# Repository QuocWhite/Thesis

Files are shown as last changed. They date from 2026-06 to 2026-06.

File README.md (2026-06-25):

# Quoc — Voice-Guided 6-DOF Robotic Arm Control System

Python-based control system for a **6-DOF pick-and-place robot arm** with voice commands, computer vision (YOLOv3), inverse kinematics, and ESP32 firmware (Arduino framework).

## System Overview

```
User Voice → Speech Recognition → Command Parsing → Object Detection (YOLO)
                                                       ↓
                                              Inverse Kinematics
                                                       ↓
                                            Serial → ESP32
                                                       ↓
                                           PCA9685 → 6 Servo Motors
```

## 6-DOF Joint Configuration (Denavit-Hartenberg)

| Joint | Name | Type | DH a (mm) | DH d (mm) | α | Serial Label |
|---|---|---|---|---|---|---|
| J1 | Base | Waist | 42 | 75 | +90° | `b` |
| J2 | Right | Shoulder | 95 | 0 | 0° | `r` |
| J3 | Left | Elbow | 18 | 0 | +90° | `l` |
| J4 | Twist | Wrist roll | 0 | 166 | -90° | `t` |
| J5 | Wrist | Wrist pitch | 0 | 0 | +90° | `w` |
| J6 | Finger | Gripper  | 0 | 27 | +180° | `f` |

## Project Structure

```
Quoc/
├── voice/                      Speech recognition (Google STT + noise reduction)
│   └── VoiceRecognization.py
├── vision/                     YOLOv3 object detection
│   ├── yolo.py                 2D detection → pixel coordinates
│   └── yolo3/                  YOLOv3 model architecture
├── kinematics/                 Forward & inverse kinematics
│   └── kinematics.py           DH parameters, Jacobian-based IK solver
├── actuator/                   ESP32 firmware (Arduino framework) & 3D print files
│   ├── ArmControl/             Firmware source (C++)
│   │   ├── ArmControl.ino      Entry point
│   │   ├── ArmControl.h        Configuration, pin assignments, class API
│   │   └── ArmControl.cpp      6-axis motion control, cubic trajectory, serial parser
│   └── Finger/                 3D-printable gripper STL files
├── command/                    Serial communication bridge
│   └── command_handeler.py     Sends joint data & commands to ESP32
├── Test/                       Host-side integration & unit tests
│   ├── test_system.py          Kinematics, serial bridge, voice parsing, pipeline, 3D viz
│   ├── test_armcontrol.py      Python port of firmware logic (18 unit/stress tests)
│   ├── armcontrol.py           Python port of firmware TrajectoryQueue
│   ├── Arm_IT_test.cpp         C++ host endurance test (10k steps)
│   ├── Arm                     Compiled C++ test binary
│   ├── arm_fk_plot.png         Generated 3D FK visualization
│   └── arm_ik_plot.png         Generated IK convergence plot
├── main.py                     Pipeline entry point
├── run_sys.sh                  Startup script (activates venv, runs main.py)
└── requirements.txt
```

## Firmware (ESP32)

### Communication Protocol

Serial at **115200 baud** on `/dev/ttyUSB0` (configurable).

**Joint angle format:** `b<base>r<right>l<left>t<twist>w<wrist>f<finger>\n`

Example: `b90r45l60t0w30f50\n` sets all 6 joints.

**Text commands:**
| Command | Action |
|---|---|
| `init` | Reset all joints to factory home |
| `report` | Print current joint positions |
| `test` | Run servo sweep test |
| `mcalib` | Read manual calibration data |
| `acalib` | Run auto calibration |

### Motion Control

- **Servo driver:** PCA9685 16-channel PWM controller (I²C)
- **Cubic trajectory interpolation:** Smooth point-to-point motion with configurable duration (150 ms per segment)
- **Trajectory queue:** 2D circular buffer (`queueBuffer_[MAX_JOINT][TRAJECTORY_QUEUE_SIZE]`) for multi-step sequences
- **Joint limits:** Configurable min/max pulse widths per joint via hardware trigger pins
- **EEPROM calibration:** Stores calibrated pulse ranges persistently

### Firmware Fixes Applied

The C++ firmware (`ArmControl.h`/`.cpp`) received the following fixes:
- **Dead macro removal:** 6 unused macros removed from `ArmControl.h`
- **Typo correction:** `MED_DEVIDE` renamed to `MIDPOINT_DIV`
- **Semantic rename:** 3 misleading names (`QUEUE_ERROR`→`QUEUE_ERR`, `UNAVAIL_SER`→`SER_ERR`, `INCREASE`→`INC_STEP`) — private methods in `ArmControl.cpp`
- **Private method naming:** 15 methods unified to camelCase convention
- **Integer overflow fix:** 5 overflow bugs in `computeCubicTrajectory_` fixed with `int64_t` casts to prevent wrap-around on large intermediate products
- **Output clamping:** Cubic interpolation results clamped to `[COMMON_MIN_ANGLE, COMMON_MAX_ANGLE]` to protect servos from overshoot

### Hardware Pin Mapping

Each joint has dedicated trigger pins for limit/calibration:

| Joint  | Min Pin | Max Pin | PCA9685 Channel |
|---|---|---|---|
| Base | 12 | 5 | 0 |
| Right  | 14 | 13 | 1 |
| Left | 19 | 18 | 2 |
| Twist  | 26 | 25 | 3 |
| Wrist  | 32 | 27 | 4 |
| Finger | 4 | 33 | 5 |

## Python Components

### Voice (`voice/VoiceRecognization.py`)
- Google Speech Recognition API
- Real-time noise reduction via `noisereduce`
- Keyword extraction for actions: *take, pick, grab, get*

### Vision (`vision/yolo.py`)
- YOLOv3 object detection (TensorFlow 2 / Keras)
- 2D pixel coordinates from webcam feed
- COCO dataset classes (80 object categories)

### Kinematics (`kinematics/kinematics.py`)
- Forward kinematics via DH parameter transformation matrices
- Inverse kinematics via Jacobian pseudoinverse (damped least-squares)
- Euler angle extraction from rotation matrices
- Configurable iteration count, tolerance, and learning rate
- Numerical Jacobian via finite-difference perturbation (fixed: input arrays auto-cast to float to prevent integer truncation of perturbations)

### Tests (`Test/`)
- **`test_system.py`** — 16 integration tests:
  - 4 kinematics tests: FK at zero (checking x≈155, y≈0, z≈−118 per DH convention), FK at known angles, IK roundtrip (solve → FK → error < 1.0), Jacobian shape (6×6) and rank validation
  - 3 serial bridge tests (mocked): protocol format verification, text commands, concatenated sends
  - 6 voice parsing tests (conditionally skipped without `noisereduce`): action/object extraction for *take/pick/grab/get*, case insensitivity, no-action
  - 1 full pipeline test: mocked voice → YOLO → IK → serial → roundtrip verification
  - 2 3D visualization tests: `arm_fk_plot.png` (3-configuration arm layout), `arm_ik_plot.png` (convergence curve + solved arm)
- **`test_armcontrol.py`** — 18 unit/stress tests for the Python firmware port (edge-case clamping, trajectory queue overflow, cubic interpolation)
- **`armcontrol.py`** — Python port of `TrajectoryQueue` with 2D circular buffer
- **`Arm_IT_test.cpp`** — C++ host endurance test (10k iterations, all 7 tests passing)

### Command Bridge (`command/command_handeler.py`)
- Serial communication with ESP32
- `send_joint_data(t1..t6)` — sends formatted joint angles
- `send_command(cmd)` — sends text commands
- Response reading and logging

## Setup

```bash
pip install -r requirements.txt
./run_sys.sh
```

Requires **Python 3.10+** and an **ESP32** running the firmware at `/dev/ttyUSB0` (configurable in `command/command_handeler.py`).

### Firmware Upload

1. Open `actuator/ArmControl/ArmControl.ino` in Arduino IDE
2. Install dependencies: `Adafruit PWMServoDriver` library
3. Select **ESP32 Dev Module** board (install ESP32 board support if needed)
4. Upload to the appropriate serial port (e.g. `/dev/ttyUSB0`)

## 3D-Printable Parts

Gripper STL files in `actuator/Finger/`:
- Palm (top & bottom)
- Finger pads & hinge arms
- Left/right gear arms
- Servo gear components

## Requirements

- Python 3.10+
- ESP32 (Arduino framework)
- PCA9685 servo driver
- 6× servo motors (with limit switches)
- USB webcam
- Microphone

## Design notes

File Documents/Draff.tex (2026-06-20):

\documentclass[12pt,a4paper]{report}

\usepackage{tikz}
\usepackage{amsmath}
\usepackage{listings}
\usepackage{hyperref}
\usepackage{geometry}
\geometry{margin=1in}

\title{Robotic Arm Thesis\\Actuator Subsystem Report}
\author{Your Name}
\date{\today}

\begin{document}

\maketitle

\tableofcontents

\chapter{Actuator System: Firmware Architecture and Control Algorithms}

\section{Introduction}
The actuator subsystem is implemented on an Arduino-compatible microcontroller, utilizing the Adafruit PCA9685 16-channel PWM driver for servo control. Its main function is to convert high-level trajectory commands into precise joint movements. This chapter details the firmware structure, data flow, control algorithms, calibration methods, and feedback integration, as derived directly from the provided source code.

\section{System Architecture Diagram}
Figure~\ref{fig:actuator_architecture} illustrates the actuator system architecture. The main components are: joint mapping, trajectory queue, servo driver, calibration routines, EEPROM storage, and sensor feedback.

\begin{figure}[h]
    \centering
    \begin{tikzpicture}[node distance=1.7cm,>=stealth,thick]
        % Nodes
        \node[draw,rounded corners,fill=blue!10] (serial) {Serial Interface};
        \node[draw,rounded corners,below of=serial,fill=green!10] (cmdparser) {Command Parser};
        \node[draw,rounded corners,right=3.5cm of cmdparser,fill=yellow!10] (eeprom) {EEPROM Storage};
        \node[draw,rounded corners,below of=cmdparser,fill=orange!20] (queue) {Trajectory Queue};
        \node[draw,rounded corners,below of=queue,fill=red!10] (motion) {Motion State Manager};
        \node[draw,rounded corners,left=3.5cm of motion,fill=purple!10] (calib) {Calibration \& Feedback};
        \node[draw,rounded corners,below of=motion,fill=cyan!10] (servo) {PWM Servo Driver};
        \node[draw,rounded corners,below of=servo,fill=gray!20] (joints) {Arm Joints};

        % Connections
        \draw[->] (serial) -- (cmdparser);
        \draw[->] (cmdparser) -- (queue);
        \draw[->] (cmdparser) -- (eeprom);
        \draw[->] (queue) -- (motion);
        \draw[->] (motion) -- (servo);
        \draw[->] (servo) -- (joints);
        \draw[->] (calib) -- (motion);
        \draw[->] (joints) -- (calib);
        \draw[->] (calib) -- (eeprom);

        % Labels
        \node[above of=serial,node distance=1cm] {\textbf{Actuator System Overview}};
    \end{tikzpicture}
    \caption{Actuator firmware architecture: data flow and module interconnection.}
    \label{fig:actuator_architecture}
\end{figure}

\section{Joint and Servo Configuration}
Each joint (base, right, left, twist, wrist, finger) is mapped to a servo channel. The configuration parameters (e.g., min/max pulse widths, angle values) are defined in the firmware header. Factory settings and joint limits ensure safe operation:
\begin{itemize}
    \item \textbf{Servo pulse range:} 320--2570 $\mu$s, corresponding to 0--180 degrees.
    \item \textbf{Joint channels:} BASE=0, RIGHT=1, LEFT=2, TWIST=3, WRIST=4, FINGER=5.
    \item \textbf{Factory values:} BASE = 1455 $\mu$s, RIGHT = 732 $\mu$s, etc.
\end{itemize}

\section{Firmware Main Loop Flowchart}

\begin{figure}[h]
    \centering
    \begin{tikzpicture}[node distance=1.7cm,>=stealth,thick]
        % Nodes
        \node[draw,rounded corners,fill=blue!10] (start) {Start / Reset};
        \node[draw,rounded corners,below of=start,fill=green!10] (init) {initialize()};
        \node[draw,rounded corners,below of=init,fill=yellow!10] (loop) {loop()};
        \node[draw,rounded corners,below of=loop,fill=purple!10] (serialcmd) {handleSerialCommands()};
        \node[draw,rounded corners,below of=serialcmd,fill=orange!10] (motion) {updateMotion()};
        \node[draw,rounded corners,below of=motion,fill=red!10] (end) {End / Repeat};

        % Connections
        \draw[->] (start) -- (init);
        \draw[->] (init) -- (loop);
        \draw[->] (loop) -- (serialcmd);
        \draw[->] (serialcmd) -- (motion);
        \draw[->] (motion) -- (end);
        \draw[->] (end) -- (loop);

        % Labels
        \node[above of=start,node distance=1cm] {\textbf{Firmware Main Loop}};
    \end{tikzpicture}
    \caption{Firmware main loop: initialization, command handling, and motion update.}
    \label{fig:main_loop}
\end{figure}

\section{Trajectory Planning and Cubic Interpolation}
Trajectory motion is managed via queue structure for each joint. When a motion command is enqueued, the system computes smooth transitions using cubic polynomial interpolation.

\subsection{Cubic Trajectory Equation}
The core cubic trajectory generation function uses the following equation:
\begin{align}
\mathrm{pos}(t) = a_0 + a_1 t + a_2 t^2 + a_3 t^3
\end{align}
where coefficients are:
\begin{align*}
    a_0 &= \mathrm{startPos} \cdot 1000 \\
    a_1 &= 0 \\
    a_2 &= \frac{3 \cdot \Delta \cdot 1000000}{T^2} \\
    a_3 &= \frac{-2 \cdot \Delta \cdot 1000000000}{T^3}
\end{align*}
where $\Delta = \mathrm{endPos} - \mathrm{startPos}$ and $T$ is the total motion duration (150 ms).

\section{Actuator State Diagram (Joint Motion)}

\begin{figure}[h]
    \centering
    \begin{tikzpicture}[node distance=2.2cm,>=stealth,thick]
        % States
        \node[draw,rounded corners,fill=blue!10] (idle) {Idle};
        \node[draw,rounded corners,right=3.5cm of idle,fill=green!10] (enqueue) {Enqueue Trajectory};
        \node[draw,rounded corners,below of=enqueue,fill=yellow!10] (interpolate) {Interpolate Motion};
        \node[draw,rounded corners,below of=interpolate,fill=orange!10] (servo) {Update Servo Position};
        \node[draw,rounded corners,left=3.5cm of servo,fill=purple!10] (complete) {Motion Complete};
        \node[draw,rounded corners,above of=complete,fill=red!10] (calib) {Calibration / Feedback};

        % Connections
        \draw[->] (idle) -- node[above] {Command Received} (enqueue);
        \draw[->] (enqueue) -- (interpolate);
        \draw[->] (interpolate) -- (servo);
        \draw[->] (servo) -- node[right] {if complete} (complete);
        \draw[->] (complete) -- node[left] {next command} (enqueue);
        \draw[->] (servo) -- node[below] {if not complete} (interpolate);
        \draw[->,dashed] (calib) -- (servo);

        % Labels
        \node[above of=idle,node distance=1cm] {\textbf{Actuator State Diagram}};
    \end{tikzpicture}
    \caption{State diagram for joint motion: command, interpolation, servo update, and completion.}
    \label{fig:actuator_state_diagram}
\end{figure}

\section{Angle/Pulse Conversion Equations}

\subsection{Angle to Pulse Conversion}
\begin{equation}
\text{Pulse} = \frac{(\text{Angle} - \text{SERVO\_MIN\_SOURCE}) \cdot (\text{MaxTarget} - \text{MinTarget})}{\text{SERVO\_MAX\_SOURCE} - \text{SERVO\_MIN\_SOURCE}} + \text{MinTarget}
\end{equation}

\subsection{Pulse to Angle Conversion}
\begin{equation}
\text{Angle} = \frac{(\text{Pulse} - \text{MinTarget}) \cdot (\text{SERVO\_MAX\_SOURCE} - \text{SERVO\_MIN\_SOURCE})}{\text{MaxTarget} - \text{MinTarget}} + \text{SERVO\_MIN\_SOURCE}
\end{equation}

\section{Calibration and Feedback}
Calibration is performed in two ways:
\begin{itemize}
    \item \textbf{Manual Calibration:} User sends calibration data via serial, which is written to EEPROM.
    \item \textbf{Auto Calibration:} System moves each joint to its limit while reading sensor-trigger pins to record the travel points.
\end{itemize}
EEPROM operations ensure calibration persists across power cycles. The relevant addresses and magic values are defined for robust identification and storage.

Trigger pins (digital inputs) are mapped per joint and per limit (min/max). During auto calibration, the firmware sweeps each joint until the sensor is triggered, recording the pulse value at that point. This feedback loop ensures accurate physical limits and compensates for hardware tolerances.

\section{Robustness and Safety}
\begin{itemize}
    \item \textbf{Constraint checks:} \texttt{ConsTrain()} ensures angles/pulses stay within safe hardware limits.
    \item \textbf{Magic values:} Used in EEPROM to verify calibration data integrity.
    \item \textbf{Feedback sensors:} Minimize the risk of over-travel and hardware damage.
\end{itemize}

\section{Summary}
The actuator firmware provides a robust, scalable, and precise motion control foundation for the robotic arm. Key features include:
\begin{itemize}
    \item Modular joint and servo abstraction.
    \item Queue-based trajectory planning and cubic interpolation.
    \item Sensor feedback for calibration and safety.
    \item Persistent storage of calibration data via EEPROM.
    \item Extensible command interface for integration with vision and voice modules.
\end{itemize}
This system enables reliable and accurate manipulation essential for tasks such as pick-and-place, and sets the groundwork for higher-level autonomous control.

\begin{thebibliography}{9}
\bibitem{citation1} Arduino actuator and trajectory control principles, as implemented in ArmControl.cpp, ArmControl.h, and ArmControl.ino.
\end{thebibliography}

\end{document}

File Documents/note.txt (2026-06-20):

The study attempt to investigate the Voice-Guided Robotic Arm Manipulation System that seamlessly integrates speech recognition technologies with automated robotic control. The system architecture begins with user voice input, which is captured via a microphone and converted to text using speech-to-text engines. Parsed commands are interpreted using natural language processing or keyword-based methods to extract actionable instructions. Visual input from a camera is processed using pre-trained computer vision models of YOLO for object detection and localization. The robotic arm, controlled via an Arduino and PCA9685 interface, receives precise movement commands based on matched object coordinates and performs pick-and-place or other manipulation tasks. The system further incorporates sensor feedback for robust error correction and reliable operation. This multidisciplinary approach demonstrates the feasibility and effectiveness of intuitive, voice-driven interaction with robotic manipulators, bridging advancements in speech recognition, computer vision, and mechatronic control systems.

This research integrates speech recognition and computer vision into robotic arms to enable more natural and flexible human control. By using voice commands and real-time visual feedback, the system improves usability and adaptability compared to traditional interfaces, making robotic arms more practical for dynamic environments like manufacturing and healthcare.

init :
90 20 100 95 150 150
rotate :
180 20 100 95 150 50
ground :
180 90 36 95 80 50
grab :
180 90 36 95 80 145
up :
180 20 100 95 150 145
give :
0 20 100 95 150 145
put :
0 20 100 95 150 50

init :
90 100 20 95 150 150
rotate :
120 100 20 95 150 50
ground :
120 36 90 95 80 50
grab :
120 36 90 95 80 145
up :
120 100 20 95 150 145
give :
0 100 20 95 150 145
put :
0 100 20 95 150 50

120 36 90 95 80 50

new hardware
init :
92, 29, 108, 92, 90, 0

ground :
90 40 100 95 0 0

90 50 90 95 0 0

90 60 80 95 0 0

90 70 70 95 0 0

90 80 60 95 0 0

90 85 65 95 0 0

90 90 50 95 0 0

90 97 50 95 0 0

90 97 50 95 0 0
90 97 50 95 0 0
90 97 47 95 0 0

90 97 45 95 90 0

def take_obj1():
    # rotate :
    send_joint_data(180, 100, 20, 95, 150, 50)
    time.sleep(2)
    # ground
    send_joint_data(180, 36, 90, 95, 80, 50)
    time.sleep(2)
    # grab
    send_joint_data(180, 36, 90, 95, 80, 145)
    time.sleep(2)
    # up
    send_joint_data(180, 100, 20, 95, 150, 145)
    time.sleep(2)
    # to box
    send_joint_data(0, 100, 20, 95, 150, 145)
    time.sleep(2)
    # place
    send_joint_data(0, 100, 20, 95, 150, 50)
    time.sleep(2)
    send_joint_data(90, 100, 20, 95, 150, 150)

def take_obj2():
    # rotate :
    send_joint_data(120, 100, 20, 95, 150, 50)
    time.sleep(2)
    # ground
    send_joint_data(120, 36, 90, 95, 80, 50)
    time.sleep(2)
    # grab
    send_joint_data(120, 36, 90, 95, 80, 145)
    time.sleep(2)
    # up
    send_joint_data(120, 100, 20, 95, 150, 145)
    time.sleep(2)
    # to box
    send_joint_data(0, 100, 20, 95, 150, 145)
    time.sleep(2)
    # place
    send_joint_data(0, 100, 20, 95, 150, 50)
    time.sleep(2)
    send_joint_data(90, 100, 20, 95, 150, 150)

def listen_and_recognize():
    recognizer = sr.Recognizer()
    with sr.Microphone() as source:
        print("Record .")
        audio = recognizer.listen(source)
        # Convert audio to numpy array for processing
        audio_data = np.frombuffer(audio.get_raw_data(), np.int16)
        # Reduce noise
        reduced_noise = nr.reduce_noise(y=audio_data, sr=16000)
        # Convert back to AudioData for recognition
        audio = sr.AudioData(reduced_noise.tobytes(),
                             audio.sample_rate, audio.sample_width)
    try:
        text = recognizer.recognize_google(audio)
        return text
    except sr.UnknownValueError:
        return None
    except sr.RequestError:
        return None

def extract_command(text):
    text = text.lower()
    actions = ['take', 'pick', 'grab', 'get']
    action = None
    for act in actions:
        if act in text:
            action = act
            break
    if action:
        # Remove polite words and the action
        for prefix in ['please', 'could you', 'would you']:
            text = text.replace(prefix, '')
        # Remove action
        text = text.replace(action, '', 1)
        object_ = text.strip()
        print(f'action: {action}')
        print(f'object: {object_}')
        return action
    else:
        print("No action found in the command.")
        return None

print("Please give me the command: ")

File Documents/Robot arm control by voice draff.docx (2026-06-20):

Robot arm control by voice draff:

how it works?

User Voice

↓

Voice Recognition

↓

Command Parsing

↓

Object Detection (Camera + CV)

↓

Robotic Arm Control Logic

↓

Actuation (pick/place/move)

1. Voice recognition:

Microphone Input: Record voice commands.

Speech-to-Text (STT): Convert voice to text using:

- Offline: Vosk, PocketSphinx, speechrecognition
- Online: Google Speech-to-Text, Whisper API

2. Command Parsing:

- Use NLP or keyword-based parsing.
- Example: "Pick up the red ball" → {"action": "pick", "object": "red ball"}

3. Object Detection (Camera + CV)

Camera Setup:

- Use Laptop and USB webcam to capture video.
- Use a webcam or Raspberry Pi camera to capture video.

Object Detection:

- Use pre-trained models (YOLO, SSD, etc.).
- Train a custom model.

Object Localization:

- Convert pixel positions to real-world coordinates.
- Use calibration and perspective transformation in some cases.

4. Actuation :

Working principles:

Defining the coordinate systems.

Determining the desired end-effector position and orientation.

Calculating the required joint angles (inverse kinematics).

Planning a smooth trajectory.

Implementing control algorithms to achieve the desired movement.

Using sensors for feedback and error correction.

Hardware Interface:

- Use Arduino to control servos.

Pick and Place Logic:

- Match object coordinates from vision with reachable positions.
- Move the arm accordingly.

This is the state diagram for the arm:

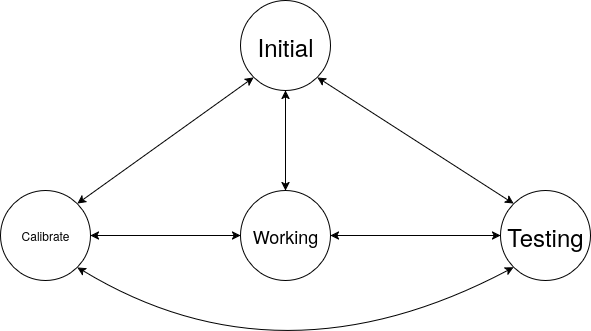
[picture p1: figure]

Initial : a state that is the end point of the arm at the initialize which is (0;0;0) in the 3D coordinate system.

working: a state that is the arm in the working base on a given coordinate.

Testing : a state that the arm will be testing all servos independent from that can diagnose the fault of each joint.

Calibrate: a state that each servo checking itself to confirm a value suitable for movement and write it to eeprom.

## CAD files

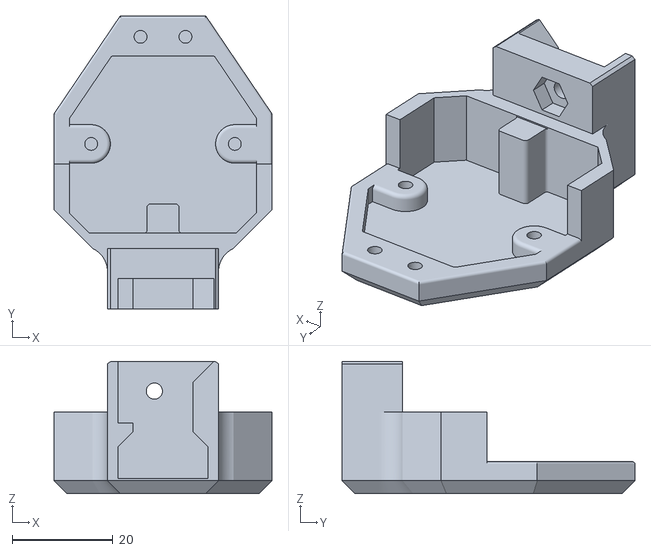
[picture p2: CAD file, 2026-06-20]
actuator/Finger/Robotic_Arm_Palm.stl
43.2 x 58.0 x 26.2

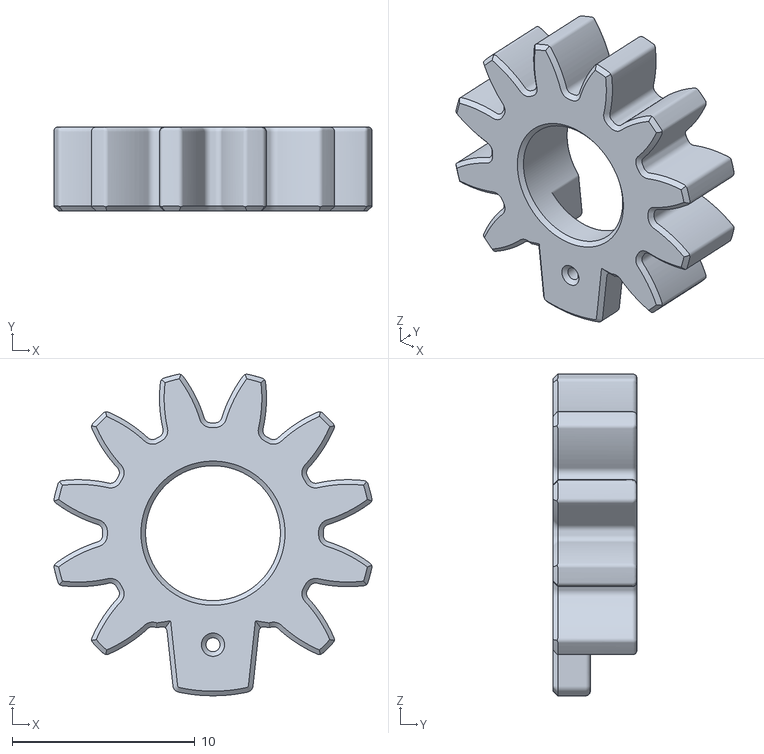
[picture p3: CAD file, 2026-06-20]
actuator/Finger/Robotic_Arm_Servo_Gear.stl
17.4 x 4.57 x 17.6

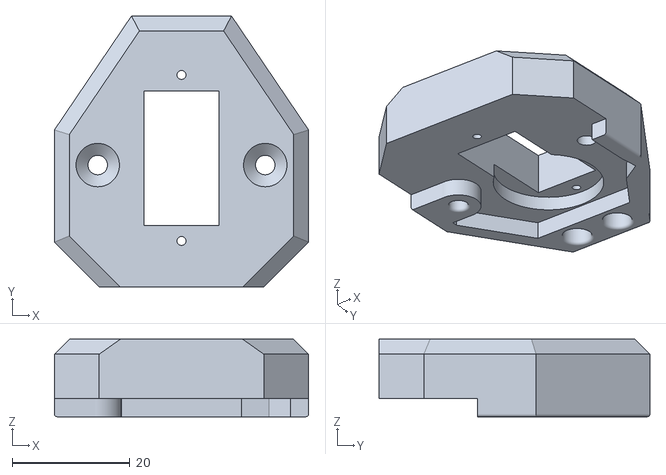
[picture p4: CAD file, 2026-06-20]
actuator/Finger/Robotic_Arm_Palm_Top.stl
43.2 x 46.0 x 13.2

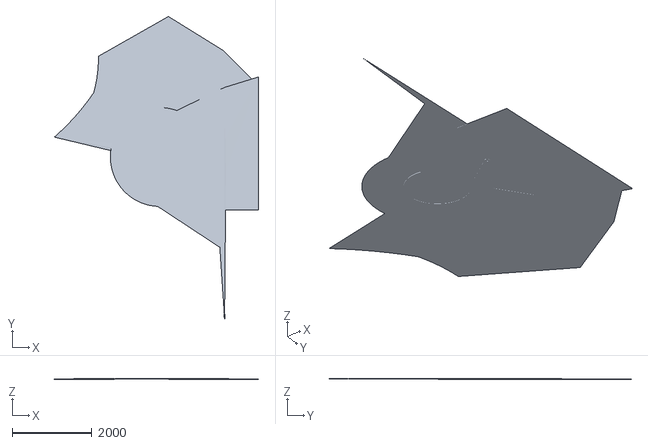
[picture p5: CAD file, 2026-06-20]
actuator/Finger/Robotic_Arm_Palm_Top_fixed.stl
5115.8 x 7560.5 x 13.2

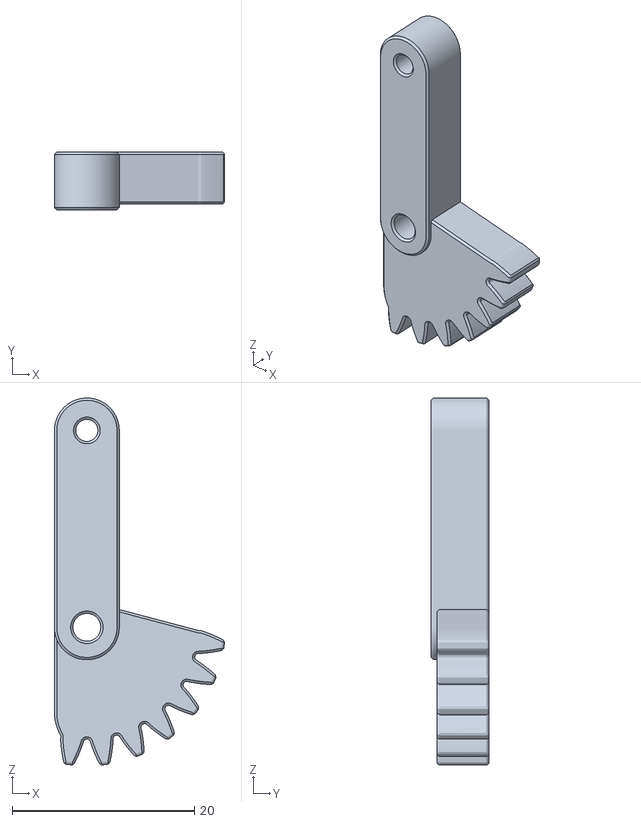
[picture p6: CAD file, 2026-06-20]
actuator/Finger/Robotic_Arm_Gear_Arm_Left.stl
18.7 x 6.35 x 40.2

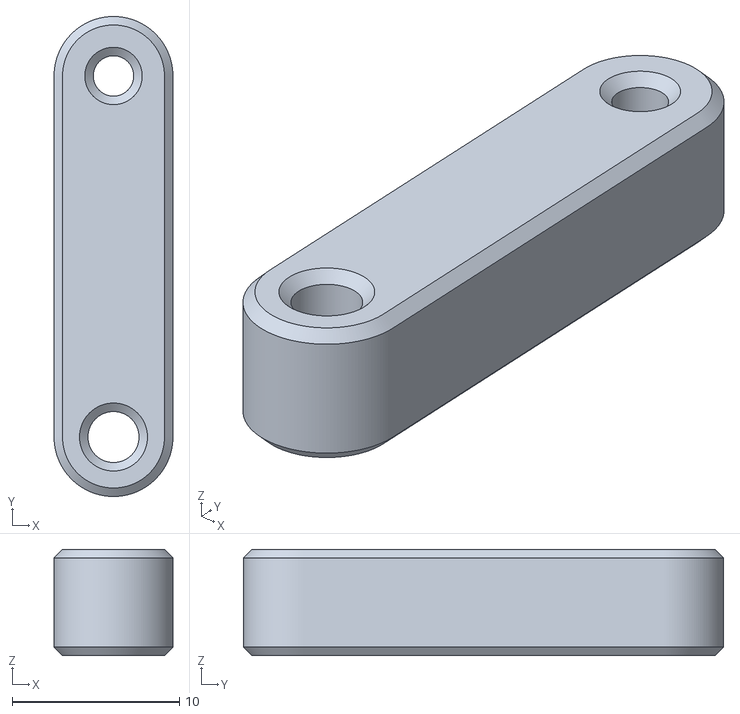
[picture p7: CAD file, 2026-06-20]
actuator/Finger/Robotic_Arm_Forward_Hinge_Arm.stl
7.11 x 28.7 x 6.35

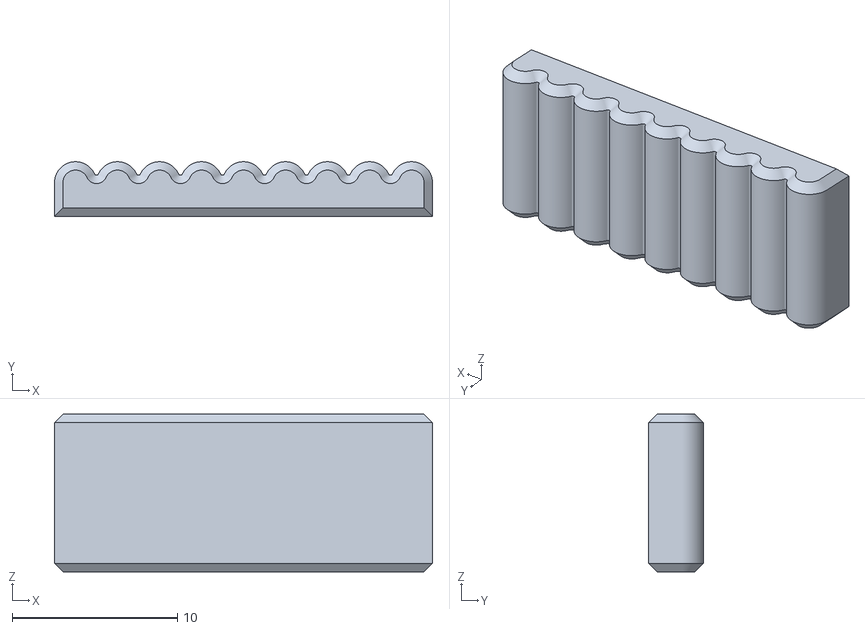
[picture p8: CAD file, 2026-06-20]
actuator/Finger/Robotic_Arm_Finger_Pad.stl
22.9 x 3.30 x 9.53

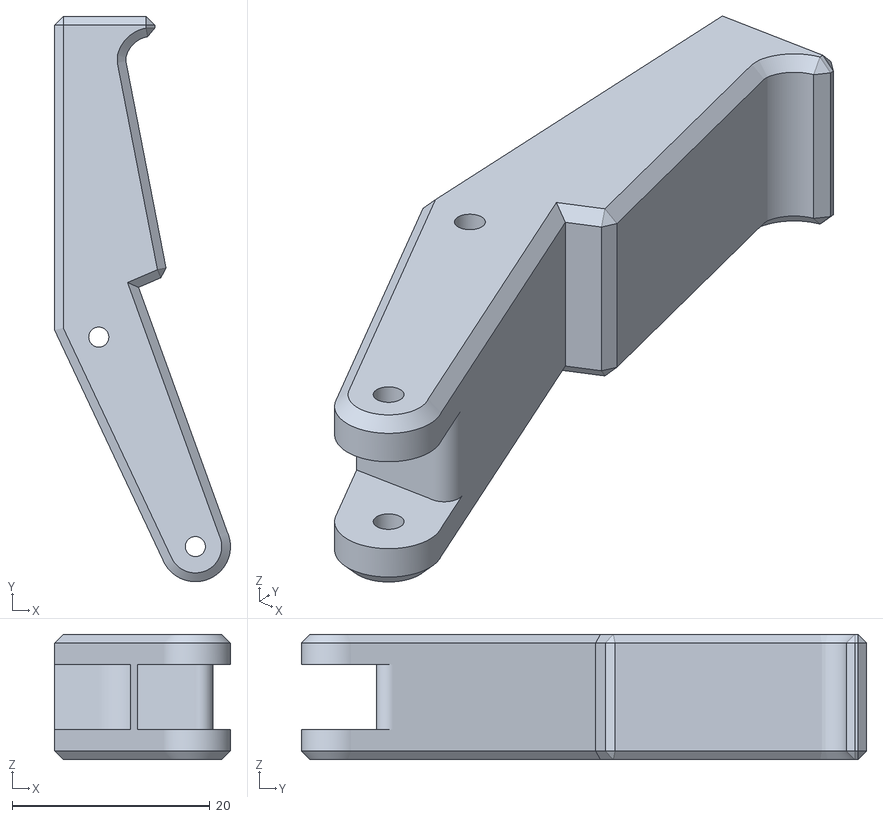
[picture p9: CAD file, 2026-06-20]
actuator/Finger/Robotic_Arm_Finger.stl
17.8 x 57.2 x 12.7

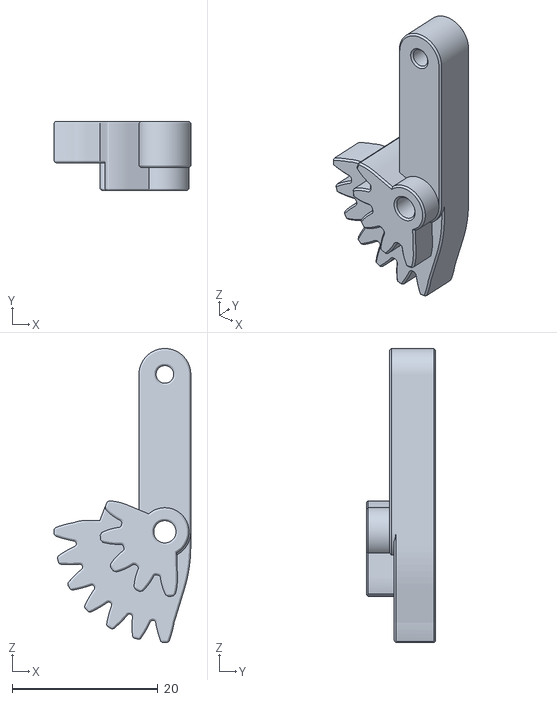
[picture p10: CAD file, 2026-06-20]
actuator/Finger/Robotic_Arm_Gear_Arm_Right.stl
18.7 x 9.53 x 40.3

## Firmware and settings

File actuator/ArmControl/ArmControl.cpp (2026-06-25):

#include "ArmControl.h"

/* ================================================================= */
/* ===                      Constructor                          === */
/* ================================================================= */

ArmControl::ArmControl()
: servoDriver_()
{
  FactoryInit_[BASE]   = FACT_BASE_ANGLE_VAL;
  FactoryInit_[RIGHT]  = FACT_RIGHT_ANGLE_VAL;
  FactoryInit_[LEFT]   = FACT_LEFT_ANGLE_VAL;
  FactoryInit_[TWIST]  = FACT_TWIST_ANGLE_VAL;
  FactoryInit_[WRIST]  = FACT_WRIST_ANGLE_VAL;
  FactoryInit_[FINGER] = FACT_FINGER_ANGLE_VAL;

  JointChannels_[BASE]   = BASE_JOINT;
  JointChannels_[RIGHT]  = RIGHT_JOINT;
  JointChannels_[LEFT]   = LEFT_JOINT;
  JointChannels_[TWIST]  = TWIST_JOINT;
  JointChannels_[WRIST]  = WRIST_JOINT;
  JointChannels_[FINGER] = FINGER_JOINT;

  BaseAngle_[PIN_MIN]   = BASE_MIN_ANGLE_PIN;
  BaseAngle_[PIN_MAX]   = BASE_MAX_ANGLE_PIN;
  RightAngle_[PIN_MIN]  = RIGHT_MIN_ANGLE_PIN;
  RightAngle_[PIN_MAX]  = RIGHT_MAX_ANGLE_PIN;
  LeftAngle_[PIN_MIN]   = LEFT_MIN_ANGLE_PIN;
  LeftAngle_[PIN_MAX]   = LEFT_MAX_ANGLE_PIN;
  TwistAngle_[PIN_MIN]  = TWIST_MIN_ANGLE_PIN;
  TwistAngle_[PIN_MAX]  = TWIST_MAX_ANGLE_PIN;
  WristAngle_[PIN_MIN]  = WRIST_MIN_ANGLE_PIN;
  WristAngle_[PIN_MAX]  = WRIST_MAX_ANGLE_PIN;
  FingerAngle_[PIN_MIN] = FINGER_MIN_ANGLE_PIN;
  FingerAngle_[PIN_MAX] = FINGER_MAX_ANGLE_PIN;

  PinTable_[BASE]   = BaseAngle_;
  PinTable_[RIGHT]  = RightAngle_;
  PinTable_[LEFT]   = LeftAngle_;
  PinTable_[TWIST]  = TwistAngle_;
  PinTable_[WRIST]  = WristAngle_;
  PinTable_[FINGER] = FingerAngle_;

  for (UI_8 i = FIRST_JOINT; i < MAX_JOINT; i++) {
    CurrentEEPROMValue_[i] = EMPTY_VALUE;
    UserInputJointData_[i] = EMPTY_VALUE;

    previousJointPulse_[i]  = COMMON_MIN_ANGLE;
    currentJointPulse_[i]   = COMMON_MIN_ANGLE;
    incomingJointPulse_[i]  = COMMON_MIN_ANGLE;
    jointMotionComplete_[i] = D_FALSE;

    startTime_[i]      = 0;
    lastTarget_[i]     = 0;
    currentOutput_[i]  = COMMON_MIN_ANGLE;
  }

  for (UI_8 j = FIRST_JOINT; j < MAX_JOINT; j++) {
    for (UI_8 k = 0; k < TRAJECTORY_QUEUE_SIZE; k++) {
      queueBuffer_[j][k] = EMPTY_VALUE;
    }
  }

  TrajectoryQueue_.front   = QUEUE_NULL_IDX;
  TrajectoryQueue_.rear    = QUEUE_NULL_IDX;
  TrajectoryQueue_.maxSize = TRAJECTORY_QUEUE_SIZE;

  TrajectoryQueue_.qBase[BASE]   = queueBuffer_[BASE];
  TrajectoryQueue_.qBase[RIGHT]  = queueBuffer_[RIGHT];
  TrajectoryQueue_.qBase[LEFT]   = queueBuffer_[LEFT];
  TrajectoryQueue_.qBase[TWIST]  = queueBuffer_[TWIST];
  TrajectoryQueue_.qBase[WRIST]  = queueBuffer_[WRIST];
  TrajectoryQueue_.qBase[FINGER] = queueBuffer_[FINGER];
}

/* ================================================================= */
/* ===              Conversion Helpers (Member)                   === */
/* ================================================================= */

UI_16 ArmControl::constrain_(UI_16 value)
{
  UI_16 ret;
  if (value < SERVO_MIN_SOURCE) {
    ret = SERVO_MIN_SOURCE;
  } else if (value > SERVO_MAX_SOURCE) {
    ret = SERVO_MAX_SOURCE;
  } else {
    ret = value;
  }
  return ret;
}

UI_16 ArmControl::angleToValue_(UI_16 angle, UI_16 minTarget, UI_16 maxTarget)
{
  UI_16 convertedAngle = constrain_(angle);
  UI_16 value = (convertedAngle - SERVO_MIN_SOURCE)
              * (maxTarget - minTarget)
              / (SERVO_MAX_SOURCE - SERVO_MIN_SOURCE) + minTarget;
  return value;
}

UI_16 ArmControl::valueToAngle_(UI_16 value, UI_16 minTarget, UI_16 maxTarget)
{
  UI_16 angle = ((value - minTarget) * (SERVO_MAX_SOURCE - SERVO_MIN_SOURCE))
              / (maxTarget - minTarget) + SERVO_MIN_SOURCE;
  return angle;
}

/* ================================================================= */
/* ===              Queue Utilities (Member)                      === */
/* ================================================================= */

UI_8 ArmControl::queueIsFull_(Trajectory* queue)
{
  return (queue->front == (queue->rear + INCREMENT) % queue->maxSize) ? D_TRUE : D_FALSE;
}

UI_8 ArmControl::queueIsEmpty_(Trajectory* queue)
{
  return (queue->front == QUEUE_NULL_IDX) ? D_TRUE : D_FALSE;
}

void ArmControl::enqueue_(Trajectory* queue, UI_16* data)
{
  if ((D_FALSE == queueIsFull_(queue)) || (D_TRUE == queueIsEmpty_(queue))) {
    queue->front = QUEUE_EMPTY;
    queue->rear = (queue->rear + INCREMENT) % queue->maxSize;
    for (UI_8 count = FIRST_JOINT; count < MAX_JOINT; count++) {
      queue->qBase[count][queue->rear] = data[count];
    }
  }
}

void ArmControl::dequeue_(Trajectory* queue, UI_16* dataOut)
{
  if (D_FALSE == queueIsEmpty_(queue)) {
    for (UI_8 count = FIRST_JOINT; count < MAX_JOINT; count++) {
      dataOut[count] = queue->qBase[count][queue->front];
    }
    if (queue->front == queue->rear) {
      queue->front = QUEUE_NULL_IDX;
      queue->rear  = QUEUE_NULL_IDX;
    } else {
      queue->front = (queue->front + INCREMENT) % queue->maxSize;
    }
  }
}

/* ================================================================= */
/* ===              Servo and Motion State Utilities              === */
/* ================================================================= */

void ArmControl::testAllServos_()
{
  UI_16 pulseMin = COMMON_MIN_ANGLE;
  UI_16 pulseMid = (COMMON_MIN_ANGLE + COMMON_MAX_ANGLE) / MIDPOINT_DIV;

  for (UI_8 count = FIRST_JOINT; count < MAX_JOINT; count++) {
    if (FINGER == count) {
      servoDriver_.writeMicroseconds(JointChannels_[count], FACT_FINGER_MIN_ANGLE);
      delay(DELAY_TIME);
      servoDriver_.writeMicroseconds(JointChannels_[count], FACT_FINGER_MAX_ANGLE);
      delay(DELAY_TIME);
    } else {
      servoDriver_.writeMicroseconds(JointChannels_[count], pulseMin);
      delay(DELAY_TIME);
      servoDriver_.writeMicroseconds(JointChannels_[count], pulseMid);
      delay(DELAY_TIME);
    }
  }
}

UI_8 ArmControl::isAllJointMotionComplete_()
{
  for (UI_8 count = FIRST_JOINT; count < MAX_JOINT; count++) {
    if (D_FALSE == jointMotionComplete_[count]) {
      return D_FALSE;
    }
  }
  return D_TRUE;
}

void ArmControl::prepareNextMotionStep_()
{
  for (UI_8 count = FIRST_JOINT; count < MAX_JOINT; count++) {
    previousJointPulse_[count] = currentJointPulse_[count];
    jointMotionComplete_[count] = D_FALSE;
  }
  if (D_FALSE == queueIsEmpty_(&TrajectoryQueue_)) {
    dequeue_(&TrajectoryQueue_, currentJointPulse_);
  }
}

void ArmControl::updateServoPositions_()
{
  for (UI_8 count = FIRST_JOINT; count < MAX_JOINT; count++) {
    servoDriver_.writeMicroseconds(
      JointChannels_[count],
      computeCubicTrajectory_(previousJointPulse_[count], currentJointPulse_[count], count));
  }
}
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

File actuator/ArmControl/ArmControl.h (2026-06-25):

#ifndef ARM_CONTROL_H
#define ARM_CONTROL_H

#include <Arduino.h>
#include <Wire.h>
#include <Adafruit_PWMServoDriver.h>
#include <EEPROM.h>

/* === Type Definitions === */
typedef uint8_t   UI_8;
typedef uint16_t  UI_16;
typedef int8_t    SI_8;
typedef int16_t   SI_16;
typedef int32_t   SI_32;
typedef int64_t   SI_64;


/* === Common Defines === */
#define D_FALSE     0
#define D_TRUE      1
#define OCLFRQ      27000000
#define SERCHNL     115200
#define WAITINIT    10


/* === Servo Parameters === */
#define SERVO_MIN_TARGET        320
#define SERVO_MAX_TARGET        2570
#define SERVO_FREQUENCY         50
#define MOTION_DURATION         150
#define MIDPOINT_DIV            2
#define DELAY_TIME              500

#define SERVO_MIN_SOURCE        0
#define SERVO_MAX_SOURCE        180
#define EMPTY_VALUE             0

/* === Queue Parameters === */
#define TRAJECTORY_QUEUE_SIZE   16
#define QUEUE_NULL_IDX          -1
#define INCREMENT               1

#define QUEUE_EMPTY             0
#define SERIAL_AVAIL_MIN        0

/* === Matrix/Array Dimensions === */
#define MAX_ANGLE       2
#define FIRST_JOINT     0
#define FIRST_ANGLE     0

/* === EEPROM Configuration === */
#define EEPROM_SIZE       32
#define MAGIC_ADDR        0
#define MAGIC_INIT_VAL    0x27
#define MAGIC_MODF_VAL    0x12
#define START_JOINT_ADDR  1
#define JOINT_BYTE_SIZE   2
#define MSB_OFFSET        0
#define LSB_OFFSET        1
#define SHIFT_BYTE        8
#define BYTE_MASK         0xFF

/* === System Input === */
#define PIN_MIN                     0
#define PIN_MAX                     1
#define STEP_SIZE                   5
#define DELAY_SET                   10
#define D_OFF                       0
#define D_ON                        1


#define BASE_MAX_ANGLE_PIN          5
#define BASE_MIN_ANGLE_PIN          12

#define RIGHT_MAX_ANGLE_PIN         13
#define RIGHT_MIN_ANGLE_PIN         14

#define LEFT_MAX_ANGLE_PIN          18
#define LEFT_MIN_ANGLE_PIN          19

#define TWIST_MAX_ANGLE_PIN         25
#define TWIST_MIN_ANGLE_PIN         26

#define WRIST_MAX_ANGLE_PIN         27
#define WRIST_MIN_ANGLE_PIN         32

#define FINGER_MAX_ANGLE_PIN        33
#define FINGER_MIN_ANGLE_PIN        4

/* === Joint Channel Configuration === */
#define BASE_JOINT      0
#define RIGHT_JOINT     1
#define LEFT_JOINT      2
#define TWIST_JOINT     3
#define WRIST_JOINT     4
#define FINGER_JOINT    5

/* === Joint Factory Value === */
#define COMMON_MIN_ANGLE             400
#define COMMON_MAX_ANGLE             2450

#define FACT_BASE_MIN_ANGLE          400
#define FACT_BASE_MAX_ANGLE          2450
#define FACT_BASE_ANGLE_VAL          1455

#define FACT_RIGHT_MIN_ANGLE         400
#define FACT_RIGHT_MAX_ANGLE         2450
#define FACT_RIGHT_ANGLE_VAL         732

#define FACT_LEFT_MIN_ANGLE          400
#define FACT_LEFT_MAX_ANGLE          2450
#define FACT_LEFT_ANGLE_VAL          1636

#define FACT_TWIST_MIN_ANGLE         400
#define FACT_TWIST_MAX_ANGLE         2450
#define FACT_TWIST_ANGLE_VAL         1455

#define FACT_WRIST_MIN_ANGLE         400
#define FACT_WRIST_MAX_ANGLE         2450
#define FACT_WRIST_ANGLE_VAL         1428

#define FACT_FINGER_MIN_ANGLE        500
#define FACT_FINGER_MAX_ANGLE        1560
#define FACT_FINGER_ANGLE_VAL        500

/* === Addition Compute Parameters === */
#define CUBIC_SCALE_POS     1000
#define CUBIC_SCALE_A2      1000000
#define CUBIC_SCALE_A3      1000000000
#define CUBIC_COEFF_A2      3
#define CUBIC_COEFF_A3     -2
#define CUBIC_ZERO          0


#define INIT_COMMAND     0

/* === Arm Control OOP API === */
class ArmControl {
public:
  ArmControl();

  void initialize();
  void handleSerialCommands();
  void updateMotion();

private:
  /* === Joint Index === */
  enum JointIdx : UI_8 {
    BASE = FIRST_JOINT,
    RIGHT,
    LEFT,
    TWIST,
    WRIST,
    FINGER,
    MAX_JOINT
  };

  /* === Queue === */
  struct Trajectory {
    SI_8 front;
    SI_8 rear;
    SI_8 maxSize;
    UI_16* qBase[MAX_JOINT];
  };

  /* === Command dispatch (member function pointer) === */
  typedef void (ArmControl::*CommandMethod)();

  struct CommandEntry {
    const char* name;
    CommandMethod method;
  };

  /* === Owned objects/state === */
  Adafruit_PWMServoDriver servoDriver_;

  UI_16 FactoryInit_[MAX_JOINT];
  UI_16 CurrentEEPROMValue_[MAX_JOINT];
  UI_16 UserInputJointData_[MAX_JOINT];

  UI_8 JointChannels_[MAX_JOINT];

  UI_16 queueBuffer_[MAX_JOINT][TRAJECTORY_QUEUE_SIZE];
  Trajectory TrajectoryQueue_;

  UI_16 previousJointPulse_[MAX_JOINT];
  UI_16 currentJointPulse_[MAX_JOINT];
  UI_16 incomingJointPulse_[MAX_JOINT];
  UI_8  jointMotionComplete_[MAX_JOINT];

  /* Cubic trajectory state (was static inside computeCubicTrajectory) */
  UI_16 startTime_[MAX_JOINT];
  UI_16 lastTarget_[MAX_JOINT];
  UI_16 currentOutput_[MAX_JOINT];

  /* === Pin table === */
  UI_8 BaseAngle_[MAX_ANGLE];
  UI_8 RightAngle_[MAX_ANGLE];
  UI_8 LeftAngle_[MAX_ANGLE];
  UI_8 TwistAngle_[MAX_ANGLE];
  UI_8 WristAngle_[MAX_ANGLE];
  UI_8 FingerAngle_[MAX_ANGLE];
  const UI_8* PinTable_[MAX_JOINT];

  /* === Commands table === */
  static const CommandEntry commands_[];
  static const UI_8 commandCount_;

  /* === Helpers (pure conversions) === */
  UI_16 angleToValue_(UI_16 angle, UI_16 minTarget, UI_16 maxTarget);
  UI_16 constrain_(UI_16 value);
  UI_16 valueToAngle_(UI_16 value, UI_16 minTarget, UI_16 maxTarget);

  /* === Queue helpers === */
  UI_8 queueIsFull_(Trajectory* queue);
  UI_8 queueIsEmpty_(Trajectory* queue);
  void enqueue_(Trajectory* queue, UI_16* data);
  void dequeue_(Trajectory* queue, UI_16* dataOut);

  /* === Motion helpers === */
  void testAllServos_();
  UI_8 isAllJointMotionComplete_();
  void prepareNextMotionStep_();
  void updateServoPositions_();
  UI_16 computeCubicTrajectory_(UI_16 startPos, UI_16 endPos, UI_8 jointIdx);
  void updateJointState_();
  void reportCurrentJointPositions_();

  /* === Input handling === */
  void handleDataInput_(UI_16* value, Trajectory* Queue, String rawInput);
  void readManualCalib_(UI_16* value);
  void autoCalibration_();
  UI_16 getTravelPoint_(UI_8 joint, UI_8 pin);

  /* === EEPROM utilities === */
  void writeDataToEEPROM_(const UI_16* value, UI_8 magic_val);
  void readJointDataFromEEPROM_(UI_16* value);
  void initializeEEPROM_();

  /* === Trigger input === */
  void initializeTriggerPin_();
  UI_8 getTriggerData_(UI_8 joint, UI_8 index);

  /* === Command wrappers (so command table stays simple) === */
  void cmdInit_();
  void cmdReport_();
  void cmdManualCalib_();
  void cmdAutoCalib_();
  void cmdTest_();
};


#endif

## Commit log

2026-06-20 Initial commit: 6-DOF voice-guided robotic arm control system
    - Voice control with Google Speech Recognition and noise reduction
    - YOLOv3 object detection for pick-and-place targeting
    - Forward/inverse kinematics with DH parameters and Jacobian IK
    - Arduino Mega firmware with PCA9685 servo control and cubic trajectory
    - 3D-printable gripper design files
    - Serial communication protocol for 6-axis joint control
    [Robotic_Arm_Finger.stl, Robotic_Arm_Finger_Pad.stl, Robotic_Arm_Forward_Hinge_Arm.stl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]
2026-06-24 fix(firmware): fix integer overflow, remove dead macros, unify method naming
    - Add int64_t casts in computeCubicTrajectory_ to prevent wrap-around
    - Clamp cubic output to [COMMON_MIN_ANGLE, COMMON_MAX_ANGLE]
    - Remove 6 unused macros from ArmControl.h
    - Fix typo MED_DEVIDE -> MIDPOINT_DIV
    - Rename QUEUE_ERROR/UNAVAIL_SER/INCREASE to semantic names
    - Unify 15 private methods to camelCase
    [ArmControl.cpp, ArmControl.h]
2026-06-24 fix(kinematics): prevent integer truncation in Jacobian and fix IK shape broadcast
    - Cast joint_angles_deg to float in compute_forward_kinematics
    and compute_jacobian_matrix so 1e-3 perturbations are not
    truncated to zero by integer dtype arrays
    - Reshape target_pose_vector to (6,1) in inverse_kinematics_solver
    to avoid numpy broadcast creating (6,6) pose_error from (6,) input
2026-06-24 test(Test): add system integration tests with 3D visualization, restructure to root
    - Move Test/ from actuator/ArmControl/ to project root
    - Add test_system.py with 16 tests: kinematics (FK/IK/Jacobian),
    serial bridge (mocked), voice parsing, full pipeline (mocked),
    and 3D visualization (arm_fk_plot.png, arm_ik_plot.png)
    - Update README with firmware fixes, kinematics fixes, and test docs
    - Fix PROJECT_ROOT path in test_system.py after directory move
    [test.ino]
2026-06-25 style: apply coding convention across Python and C++ sources
    - Add coding_convention.txt with merged C++ and Python rules
    - Replace magic numbers with named constants in kinematics (JOINT_COUNT,
    JACOBIAN_DELTA, EULER_SINGULARITY_THRESH), command (SERIAL_INIT_DELAY,
    RESPONSE_DELAY), voice (ACTIONS, PREFIXES, SAMPLE_RATE)
    - Factor DH table into DH_TABLE list with theta indices for readability
    - Break lines exceeding 100-char limit in ArmControl.cpp and test_armcontrol.py
    [ArmControl.cpp, command_handeler.py]
2026-06-25 style(firmware): add SI_64 typedef for int64_t and replace raw casts
    - Add typedef int64_t SI_64 in ArmControl.h matching existing UI_/SI_ pattern
    - Replace all 4 raw int64_t casts in ArmControl.cpp with SI_64
    [ArmControl.cpp, ArmControl.h]
2026-06-25 docs: correct board target from Arduino Mega to ESP32 throughout
    - README: replace all 8 Arduino Mega references with ESP32;
    update firmware upload instructions for ESP32 Dev Module
    - command/command_handeler.py: update docstrings to ESP32
    - Test files: clarify 'no physical hardware' in docstrings
    [command_handeler.py]
